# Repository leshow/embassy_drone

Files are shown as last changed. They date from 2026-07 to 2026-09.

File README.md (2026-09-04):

# mini quadcopter in Rust w/ embassy for esp32 and rp2350 (WIP)

currently still a work in progress, building a (very) mini quadcopter for esp32 on bare metal with [embassy.dev](https://embassy.dev). running on the esp32-s3 - the extra core lets the flight loop and WiFi run fully independently, and the hardware FPU matters a lot for the fusion/filter math.

## rp2350 brushless version

I've also started a version with brushless motors, a proper ESC and ELRS transmitter under [`brushless_rp2350/`](/brushless_rp2350). This one is currently WIP as well.

## Quad assets

drone frame

The frame stl & 3mf files are in the `stl/` dir and can be used to 3d print the frame. I created them in OnShape. For the battery compartment, I opted for a friction fit with pegs that you can also glue in. This got around some issues with printing supports that were a pain to remove.

There's a top stand that serves as a mount for the microcontroller and MPU6050 or ICM20948. I'll include a full parts list as the project progresses.

I've also created a prop guard you can mount as a single piece or in two halves, see the 3mf file in `stl/`

prop guard

They have a C-snap fit to the motor holders that should lock them into place pretty well. I've printed with a 0.4 and 0.6 nozzle on a bambu a1 and both results are usable. Obviously if you want cleaner layer lines go for the smaller nozzle.

I've printed in PLA, PETG and PETG-CF & GF. PLA seems totally fine, the drone frame is around ~13 grams. The prop guards are heavy at an additional 14 grams (I have a slimmed down version that still give some protection in the 3mf project file). Recommend running without the prop guards to get better battery and flight time.

## Parts list

### Microcontroller

S3-only - the earlier C3/C6 (RISC-V) builds were dropped in favor of the
S3's hardware FPU and second core. Needs the Xtensa toolchain (`espup`),
not plain `rustup` - see the ESP32-S3 section below for setup.

| Part | Chip | Cores  | Flash | RAM | WiFi | Notes |
| --- | --- | --- | ----- | --- | --- | --- |
| ESP32-S3 | ESP32-S3 | 2x LX7 | 4+ MB | 512K+PSRAM | 2.4 GHz | Current build - s3 feature |

### IMU Sensors (choose)

| Part | DOF  | Interface | Accel | Gyro | Mag | Notes |
| --- | ---- | --- | ----- | ---- | --- | --- |
| ICM-20948 | 9DOF | I²C / SPI | ✓ | ✓ | ✓ AK09916 | **Current build** - yaw via magnetometer |
| MPU-6050  | 6DOF | I²C | ✓ | ✓ | ✗ | No yaw reference; cheaper and common |

### Other Components

| Part | Qty | Notes |
| --- | --- | --- |
| 8520 brushed motor | 4 | find it on aliexpress like everything else |
| mosfet 100N03A | 4 | One per motor |
| 1S LiPo battery (3.7v) | 1 | 3.7v 1s battery 25C or more discharge rate\*  |
| Propeller | 4 | 55 or 65mm |
| 3D printed frame | 1 | STL/3MF files in `stl/` - designed in OnShape |

\*I tried with a 503040 3.7v lipo recycled from a keyboard build but the BMS (battery management system) on it will automatically shut off after a few seconds. It's not really build to power these motors.

### ESP32-S3 (default)

Needs the Xtensa toolchain, not plain `rustup`, plus [espflash](https://github.com/esp-rs/espflash) to flash and erase:

```sh
cargo install espup
espup install
# then source the exports it prints (or ~/export-esp.sh) before building

cargo install espflash
```

```sh
cargo build -p embassy_quad --target xtensa-esp32s3-none-elf
cargo run -p embassy_quad --target xtensa-esp32s3-none-elf
```

Or using the aliases:

```sh
cargo build-s3
cargo flash-s3
```

See .cargo/config.toml to see expansion of aliases

### Erase helpers

Two scripts in `scripts/` wrap `espflash erase-region` for the regions that come up most:

```sh
./scripts/erase-flash.sh        # wipes the app region (0x300000 bytes at 0x10000)
./scripts/erase-calibration.sh  # clears the nvs partition (0x6000 at 0x9000)
```

`erase-calibration` puts the accel back to "uncalibrated" by clearing partition table's `nvs`

### Log level

`DEFMT_LOG` is read at compile time by `esp-println`:

```sh
DEFMT_LOG=debug cargo flash-s3
```

### Throttle cap

`THROTTLE_CAP` sets the max throttle at compile time, it will map your throttle input from 0-100 over the range you specify. For example, if you set `THROTTLE_CAP=50` and push the throttle to 80% it will translate into `.8 * 50 = 40%`.

## Visualizer

to see a 3d rendering of the orientation run:

```bash
DEFMT_LOG="info" LOG_RATE_MS=1 cargo flash-s3 --features visualize | (cd visualizer && cargo run)
```

It feeds the esp32 log output to a binary reading stdin and rendering a cube on screen

Sensor readings from the ICM-20948 (over SPI) are sent to the ESP32-S3, where a Madgwick filter fuses accel and gyro data in software to correct orientation. (Earlier versions could also offload fusion to the ICM-20948's onboard DMP; that path has been dropped because DMP, although able to fuse mag input without calibration, is only capable of 100hz.) The icm20948's max speed is 1125hz.

```sh
DEFMT_LOG="info" LOG_RATE_MS=1 cargo flash-s3 --features visualize | (cd visualizer && cargo run)
```

## Ground control

The `ground_control/` crate is a PC-side sender that reads a gamepad and streams control packets to the drone over UDP.

The drone runs a wifi AP (`esp-quad`, WPA2) with a static IP of `192.168.4.1`. There is no DHCP server, so you must assign yourself a static IP when connecting. The trick is to do this in a single `nmcli con add` — adding security and static IP separately doesn't work reliably:

```sh
nmcli con add type wifi con-name esp-quad ssid esp-quad \
  wifi-sec.key-mgmt wpa-psk \
  wifi-sec.psk <same as AP_PASSWORD> \
  ipv4.method manual \
  ipv4.addresses "192.168.4.2/24" \
  ipv4.gateway "192.168.4.1"
```

The AP password is set at build time via the `AP_PASSWORD` environment variable. If unset, the AP is open (remove the `wifi-sec.*` lines above).

Once the profile exists, connecting is just:

```sh
nmcli dev wifi rescan
nmcli con up esp-quad
```

Then run the ground control sender:

```sh
cd ground_control && RUST_LOG="info" cargo run --release
```

The left stick Y axis controls throttle (center = 0%, full up = 100%), left stick X controls yaw, and the right stick controls pitch/roll. The Start button toggles arm. Motors only spin when armed and throttle is above 0.

The drone IP and port can be overridden at build time:

```sh
RUST_LOG="info" GATEWAY_IP=192.168.4.1 UDP_PORT=4444 cargo run --release
```

## Accelerometer Calibration

flash calibration:

```sh
DEFMT_LOG="debug" LOG_RATE_MS=100 AP_PASSWORD="testtest" cargo flash-s3 --features calibrate
```

You can then either leave the quad plugged in or unplug and calibrate using the wifi outputs, either way, you need to connect ground_control

after the `esp-quad` network shows up on wifi, connect to it and fire up ground control in calibration mode:

```sh
~/dev/rust/drone_embassy calibrate_on_wifi
❯ RUST_LOG="info" cargo gc -- --calibrate
    Finished `release` profile [optimized] target(s) in 0.02s
     Running `ground_control/target/x86_64-unknown-linux-gnu/release/ground_control --calibrate`
2026-07-19T04:19:17.472588Z  INFO ground_control: connected to 192.168.4.1:4444 - waiting to start calibration
2026-07-19T04:19:17.595122Z  WARN ground_control: place: level
2026-07-19T04:19:32.976684Z  WARN ground_control: place: front side up
2026-07-19T04:19:48.332827Z  WARN ground_control: place: back side up
2026-07-19T04:20:03.798211Z  WARN ground_control: place: right side up
2026-07-19T04:20:19.373504Z  WARN ground_control: place: left side up
2026-07-19T04:20:34.615814Z  WARN ground_control: place: upside down
2026-07-19T04:20:50.079828Z  INFO ground_control: === CALIBRATION COMPLETE - saved ===
```

follow the instructions and tilt the drone around the axis to get readings. The readings are saved in non-volatile flash memory on the esp32.

## Testing

Unit tests live in `libs`, the crate shared between `firmware` and `ground_control` that defines the control/telemetry packet wire formats. It's the only crate that can build for the host, `firmware` can't (esp-hal's build script refuses to build for a non-embedded target), so there's nothing to run tests against there yet.

`telemetry` and `telemetry-verbose` each change the telemetry packet's wire format, so they're tested separately:

```sh
cargo test -p libs
cargo test -p libs --features telemetry
cargo test -p libs --features telemetry-verbose
```

## Docs

Check the `docs/` directory for some more info on assembly, setting up different controllers, sensors, etc.

## LLM usage

Docs and tests are sometimes generated with the use of LLMs, along with explanation/discovery, but the purpose of this project is to actually learn, so the code is still written by a human (hi!)

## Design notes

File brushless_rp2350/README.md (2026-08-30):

# brushless mini quad on RP2350 (WIP)

Brushless follow-up to the main [esp32-s3 quad](../README.md) - same overall goal, different everything else. Individual ESCs instead of MOSFET-driven brushed motors, RP2350 instead of ESP32-S3, plain `rustup`/stable instead of the Xtensa toolchain, icm42688 IMU and happymodel EP2 radio instead of wifi.

Currently at the "runs fully off battery, all 4 motors spin via Oneshot125, EP2 bound to the RadioMaster Pocket" stage - no IMU, no mixer, and the control link isn't read by firmware yet (bound at the RF level, not yet parsed in code).

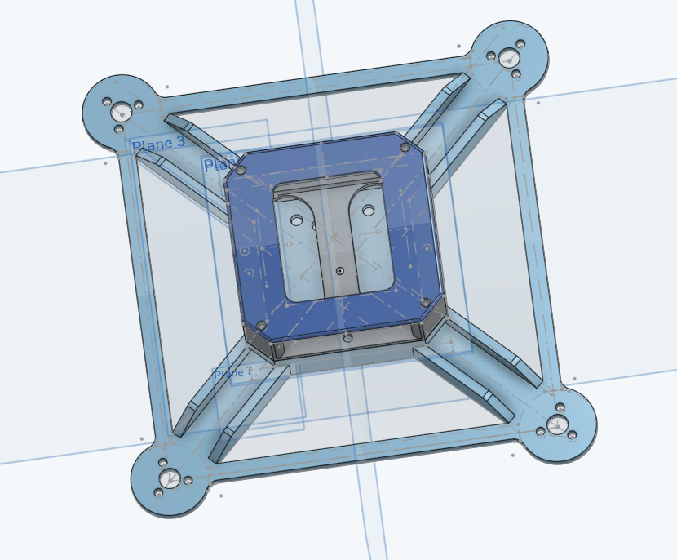
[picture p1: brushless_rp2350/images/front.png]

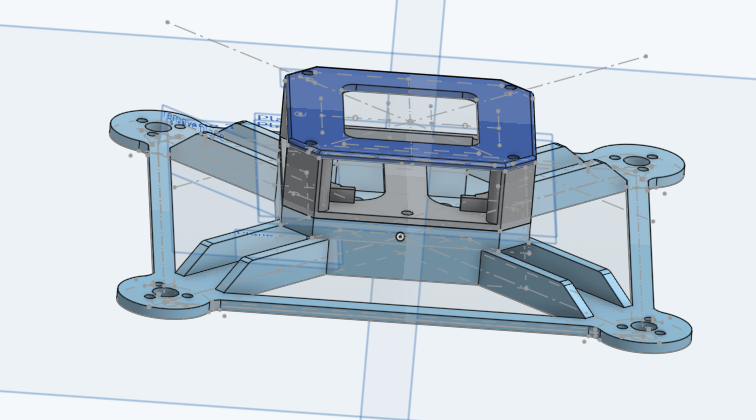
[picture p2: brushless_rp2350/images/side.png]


## Parts list (planned)

| Part | Qty | Notes |
| --- | --- | --- |
| RP2350 "mini zero" | 1 | Pro Micro-footprint clone, 29 GPIO broken out |
| Happymodel SE0802 19000KV | 4 | brushless motor, matches Mobula7 spec |
| MX-5A / MX-5A-L | 4 | individual 1S ESC, BLHeli_S/Bluejay ("BLS" in listing), one per motor |
| ICM-42688 | 1 | faster IMU |
| Happymodel Nano ELRS EP2 | 1 | ELRS receiver, CRSF over UART - pairs with the RadioMaster Pocket's built-in ELRS radio |
| 1S LiPo battery | 1 | |
| TPS63802 buck-boost module  | 1 | 1S -> 5V, powers RP2350 + EP2 - see Power section below |
| 3d printed frame in stl dir | 1 | ~70mm wheelbase, 45mm props |

## Status

- [x] single motor spins via standard servo-PWM on the bench (superseded, see below)
- [x] 4 of 4 motors spin via Oneshot125 on the bench (`src/main.rs`, GPIO10/11/12/13)
- [x] TPS63802 boost converter + EP2 wired up, whole system (RP2350 + motors) runs and arms/spins purely off battery, no USB - confirms the VSYS/power decision above works in practice
- [x] EP2 bound to the RadioMaster Pocket (solid LED) - RF link confirmed working end to end
- [x] all 4 motors + mixer (reusing `libs::mixer`)
- [x] IMU + fusion (reusing `libs::flight::fusion`)
- [x] DShot via PIO
- [ ] tune PID values

## Power

Two separate power domains:

- **Motors/ESCs**: direct off the 1S battery, unregulated - no boost converter in this path. Each MX-5A's power pads go straight to battery+/-, same raw-rail topology the brushed-motor build used minus the MOSFETs.
- **RP2350 + EP2 receiver**: 1S battery -> TPS63802 buck-boost module (5V output) -> RP2350's `VSYS` pin and the EP2's `+5V` pad, off the same boosted rail. Not `VBUS` - that's raw USB pass-through only, unavailable once flying off battery.

All grounds - battery, ESCs, RP2350, EP2, boost converter - share one common reference.

## Building

Standalone crate, not part of the root workspace - needs its own `stable` + `thumbv8m.main-none-eabihf` toolchain instead of the root's Xtensa `esp` channel.

```sh
cd brushless_rp2350
cargo build --release
```

Flash over USB/BOOTSEL (no debug probe needed - requires [picotool](https://github.com/raspberrypi/picotool)):

```sh
cargo flash-usb
```

Or, once SWD is soldered up to a debug probe, flash and get live `defmt` output:

```sh
cargo flash-probe
```

### Setting up the debug probe

For a Raspberry Pi Debug Probe or other CMSIS-DAP-compatible probe:

1. Install `probe-rs`: `cargo install probe-rs-tools --locked`
2. Linux udev rules, so the probe is accessible without root:

   ```sh
   sudo curl -fsSL https://probe.rs/files/69-probe-rs.rules -o /etc/udev/rules.d/69-probe-rs.rules
   sudo udevadm control --reload
   sudo udevadm trigger
   ```

3. Wire it up: use the probe's **"D"** (debug/SWD) port, not "U" (that's a separate plain UART). Standard 3-pin JST-SH cable: orange → SWCLK, black → GND, yellow → SWDIO. This board's SWD pins are bare pads, not a proper JST-SH connector, so you'll want the JST-SH-to-0.1"-header (female) cable variant to land on them.
4. SWD carries no power - the RP2350 still needs its own USB cable connected separately for power, same as the BOOTSEL/picotool path. So two USB cables total: one to the RP2350, one to the probe itself.
5. Raspberry Pi Debug Probes need firmware ≥2.2.0 for `probe-rs` to talk to them (older units commonly ship below that). Update via the [debugprobe releases page](https://github.com/raspberrypi/debugprobe/releases/latest): hold the probe's own BOOTSEL button while plugging it into USB, then copy `debugprobe.uf2` onto the mounted drive.
6. Sanity check before flashing: `probe-rs list` should show the probe.

See `.cargo/config.toml` for the alias definitions and notes on why the toolchain/tooling differs from the rest of the repo.

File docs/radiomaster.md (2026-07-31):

# RadioMaster Pocket as USB Gamepad for ground_control

How to configure a RadioMaster Pocket (EdgeTX) to act as a drop-in USB HID gamepad for `ground_control`, so the stick layout matches a regular Xbox-style controller with no code changes.

## Why this isn't plug and play

`ground_control` reads input through [gilrs](https://gitlab.com/gilrs-project/gilrs), which recognizes controllers by matching an SDL-style mapping database (Xbox controllers, PlayStation controllers, etc. are all in there). EdgeTX radios in USB joystick mode present a generic, fully configurable HID device under EdgeTX's own vendor ID, which is in nobody's mapping database.

Without a database entry, gilrs's Linux backend falls back to a fixed positional mapping based on the raw evdev axis/button codes (`native_ev_codes`):

| evdev code | gilrs axis/button |
| --- | --- |
| `ABS_X` | `Axis::LeftStickX`  |
| `ABS_Y` | `Axis::LeftStickY`  |
| `ABS_RX` | `Axis::RightStickX` |
| `ABS_RY` | `Axis::RightStickY` |
| `BTN_START` (0x13b)  | `Button::Start` |
| `BTN_SELECT` (0x13a) | `Button::Select` |

`ground_control` (`ground_control/src/main.rs`) maps those to controls:

- `LeftStickY` -> throttle
- `LeftStickX` -> yaw
- `RightStickX` -> roll
- `RightStickY` -> pitch
- `Button::Start` -> toggles armed (momentary press, matches a real Xbox controller's Start button)
- `Button::Select` -> armed follows the switch position directly (pressed = armed, released = disarmed), but only from a gamepad whose USB vendor/product id matches the Pocket's (`1209:4f54`) - so an Xbox controller's Back/View button, which also reports as `Button::Select`, can never trigger it

So the axis layout is just: configure the Pocket's USB joystick output to
match this table exactly, and gilrs/`ground_control` will treat it
identically to any other gamepad. The arm/disarm switch below relies on the
device-id check already built into `ground_control`, not on more config here.

## Use a dedicated Model

Do this setup in its own EdgeTX Model (Model Select screen), separate from any model you bind to a real receiver over ELRS later. Mixer, Outputs, and USB Joystick settings are all per-model in EdgeTX - nothing here can leak into a flight model, but it's one less thing to think about if the USB test config and the real flight config never share a save file.

## Advanced mode may not be available on your firmware

The instructions below assume EdgeTX's "Advanced" USB Joystick mode
(free-form per-channel axis/button picker, per-axis invert, Gamepad/Joystick
toggle). The Pocket uses an STM32F407xE chip with only 512KB flash, and since
EdgeTX 2.11 the build unconditionally disables this feature (`USBJ_EX`) for
that flash size because it doesn't fit
(`radio/src/targets/taranis/CMakeLists.txt`, confirmed in
[EdgeTX/edgetx#6434](https://github.com/EdgeTX/edgetx/issues/6434)). If the
USB Joystick page only shows Classic mode with no Advanced option, you're on
2.11+ and this is why - it's not a menu you're missing.

Three ways to proceed, roughly in order of effort:

1. **Flash EdgeTX 2.10.6** - the last release with Advanced mode intact on the
   Pocket. A normal firmware flash via EdgeTX Buddy/the bootloader, no
   building required. Since this is a new model anyway there's no old-model
   storage format to migrate. Back up the SD card first as a matter of
   course. Once on 2.10.6, follow the Advanced-mode steps below as written.
1. **Stay on stock 2.11+ firmware and use Classic mode instead** - no
   firmware changes at all, but more limited (fixed channel-to-axis order, no
   per-axis invert). See "USB Joystick setup - Classic mode" further down.

## USB Joystick setup - Advanced mode

1. Press MDL, page to SETUP
1. Set USB mode to **Advanced**
1. Set **Interface Mode** to **Gamepad**, not Joystick. This matters more than
   it sounds: Linux's HID driver maps HID button usages to a totally different
   evdev range depending on this setting (`BTN_TRIGGER`-family for Joystick,
   `BTN_SOUTH..BTN_THUMBR`-family for Gamepad). gilrs's fallback mapping only
   recognizes the Gamepad range, under Joystick mode, no button will ever
   register as `Button::Start`, no matter which number you pick.
1. In Channel Settings, assign axes by **which physical stick drives the
   channel**, not by channel number (channel order depends on your model's
   template/mode and won't match this table 1:1):

   | Control                              | Axis |
   | ------------------------------------ | ---- |
   | Rudder / yaw (left stick, horiz)     | X    |
   | Throttle (left stick, vert)          | Y    |
   | Aileron / roll (right stick, horiz)  | rotX |
   | Elevator / pitch (right stick, vert) | rotY |

   Leave every other channel `None` for now.

1. Arm/disarm: `ground_control` supports two independent controls here, wire
   up either or both:
   - **SE** (momentary button): a good fit precisely because it's momentary,
     not latching - each press cleanly toggles arm state without a mismatch
     between switch position and armed state. Pick a spare channel, set its
     source to SE, channel type **Btn**, button number **12** (HID button
     usage 12 -> evdev `BTN_START` -> gilrs `Button::Start`).
   - **SA** (2-position switch): a real latching switch, so `ground_control`
     treats it as a live level rather than a toggle - armed always matches
     SA's current position, up or down, even across a USB reconnect. Pick a
     different spare channel, set its source to SA, channel type **Btn**,
     button number **11** (HID button usage 11 -> evdev `BTN_SELECT` -> gilrs
     `Button::Select`).
1. If an axis reads backwards (e.g. throttle low at stick-up), use the invert
   control inside this same USB Joystick screen (not the Mixer's channel
   weight) - it only affects how the value is packaged into the HID report,
   not the underlying channel output other things (like a real RF link) would
   read.

After any change here, disconnect and reconnect USB, you may need to power cycle the controller too.

## USB Joystick setup - Classic mode

If you're staying on stock 2.11+ firmware (option 3 above), Classic mode has
no per-channel axis picker - it maps a fixed channel order onto axes and
buttons: **channel 1->X, 2->Y, 3->Z, 4->rotX, 5->rotY, 6->rotZ, 9-32->buttons
1-24** (button N = channel N+8). There's also no per-axis invert control - use
Mixer Weight/Offset on the channel instead. Interface Mode (Gamepad vs
Joystick) isn't selectable either, but that's fine: without `USBJ_EX` it's
hardcoded to Gamepad, which is what we want anyway (confirmed in the same
issue thread - someone without `USBJ_EX` had to hand-patch firmware source to
get Joystick type instead, meaning Gamepad is the compiled-in default).

Since Classic mode just reads whatever value ends up on a given channel
number, the trick is to **use the Mixer to put the right control on the right
channel number**, rather than assigning an axis to an existing channel:

1. In Model Setup (or Outputs page), set **Number of Channels** to at least
   **20** - channel 20 is needed for the arm button below, and the default
   model channel count usually doesn't go that high.
2. Turn off the internal/external RF module for this model (recommended by
   the EdgeTX manual for USB joystick use, and irrelevant anyway since this
   model is USB-only).
3. In the Mixer, set up these channels (delete/reassign whatever the default
   template put on CH1/2/4/5 first):

   | Channel | Source                               | -> Axis (Classic order)   |
   | ------- | ------------------------------------ | ------------------------- |
   | CH1     | Rudder / yaw (left stick, horiz)     | X                         |
   | CH2     | Throttle (left stick, vert)          | Y                         |
   | CH4     | Aileron / roll (right stick, horiz)  | rotX                      |
   | CH5     | Elevator / pitch (right stick, vert) | rotY                      |
   | CH19    | **SA** switch (2-position)           | button 11 -> `BTN_SELECT` |
   | CH20    | **SE** button (momentary)            | button 12 -> `BTN_START`  |

   Leave CH3, CH6-18 unassigned - Z/rotZ (CH3/CH6) aren't read by
   `ground_control`, and gilrs doesn't care about gaps in the button range.
   CH19/SA and CH20/SE are independent arm/disarm controls - wire up either
   or both. SE toggles arm on each press (momentary, so no
   switch-position/armed-state mismatch); SA's position is read live, so
   armed always matches wherever the switch currently sits.

4. If an axis reads backwards (e.g. throttle low at stick-up), fix it on the
   same Mixer line with **Weight -100%** instead of a dedicated invert
   control. Since this model is USB-only, inverting the real channel value
   here is fine - it doesn't feed a real RF link.
5. Optional: since a gamepad thumbstick springs back to center but the
   Pocket's throttle stick doesn't, you can use the _entire_ physical throttle
   throw for 0-100% instead of just the top half (which is what
   `ground_control` expects from a self-centering stick) by setting the CH2 mix to **Weight 50%,
   Offset +50** (adjust sign to taste). That compresses the full stick travel
   into the positive half of the reported axis, giving full resolution with
   no code changes. This trick works the same way regardless of Classic vs
   Advanced mode, since it's purely a Mixer-level rescale.

After any change here, disconnect and reconnect USB - you may need to power
cycle the controller too (see the USB wedge gotcha below).

## Verifying

Check the device enumerated correctly and has axes/buttons mapped right:

```sh
journalctl -k -n 100 | grep -i "radiomaster\|1209:4f54"
udevadm info -q property -n /dev/input/eventNN | grep ID_INPUT
```

You want to see `ID_INPUT_JOYSTICK=1`. If it's missing, the device has no axes/buttons configured yet.

Then run `ground_control` and watch its existing log lines while moving each stick and the arm button - `throttle:`, `roll:`, `pitch:`, `yaw:`, and `armed:` to confirm the mapping and polarity match a normal controller before flying anything.

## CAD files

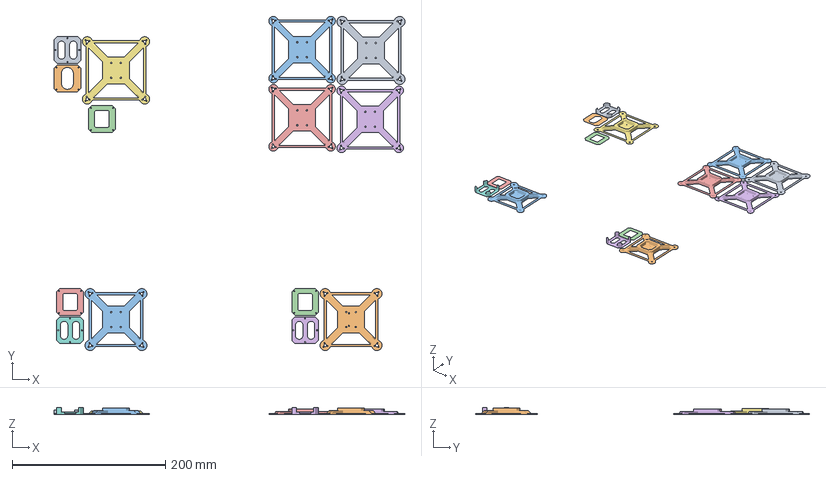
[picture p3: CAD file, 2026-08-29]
brushless_rp2350/stl/frame.3mf
458.7 x 436.7 x 9.00 mm
frame x 7
ESC x 4
top x 3

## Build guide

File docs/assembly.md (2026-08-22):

# Drone Assembly

## Parts

- ESP32-S3 board
- ICM-20948 IMU breakout
- 4× 100N03A N-channel MOSFET (one per motor)
- 4× 10kΩ resistor (gate pull-down, one per MOSFET)
- 4× 8520 brushed DC motor
- 3.3V buck-boost converter
- 2× 470μF electrolytic capacitor
- 1S LiPo battery (3.7V)
- 55mm or 65mm propellers

---

## Connection Tables

### Power

| From | To | Notes |
| --- | --- | --- |
| Battery + | Buck-boost converter IN+ | |
| Battery − | Buck-boost converter IN− | |
| Buck-boost converter 3.3V out | ESP32 3V3 pin | Feeds the S3 directly, bypassing VIN and the board's own onboard regulator - see Assembly Notes |
| Buck-boost converter GND | ESP32 GND | Common ground for all logic |
| 470μF cap (buck-boost) + | Buck-boost converter 3.3V out | Positive leg to 3.3V out |
| 470μF cap (buck-boost) − | Buck-boost converter GND | Prevents brownout during motor inrush |
| 470μF cap (battery) + | Battery + | Second cap, across the battery rail |
| 470μF cap (battery) − | Battery − | |
| Battery + | motor+ | Raw battery rail to motor switches - not through the buck-boost |
| Battery − / GND | All GND lines + mosfet source | Shared ground for motors and logic |

### ICM-20948 IMU (SPI)

Uses the ESP32-S3's actual dedicated IO_MUX FSPI pins (GPIO10-13), not
GPIO-matrix-routed ones - avoids the extra input-delay ceiling on reliable
SPI clock speed that GPIO-matrix routing would otherwise impose.

| ICM-20948  | ESP32-S3 | Notes |
| --- | --- | --- |
| VIN | 3.3V | Same net as the buck-boost's output into the ESP32-S3's 3V3 pin, tapped in parallel - not the board's own onboard regulator |
| GND | GND | |
| SDI (SDA)  | GPIO11 | SPI MOSI |
| SCLK (SCL) | GPIO12 | SPI clock |
| SDO (AD0)  | GPIO13 | SPI MISO - if AD0 was tied to a fixed level for I2C addressing, remove that tie, it's the same physical pin |
| nCS | GPIO10 | Actively driven by the ESP32, not tied to a fixed level - see Assembly Notes |
| INT | GPIO6 | Data-ready interrupt |

### Motors (via 100N03A MOSFET)

| Motor | Gate (ESP32) | Gate-Source | Drain | Source |
| --- | --- | --- | --- | --- |
| Front Left  | GPIO1 | 10k pull-down | Motor − | GND |
| Front Right | GPIO2 | 10k pull-down | Motor − | GND |
| Rear Left | GPIO4 | 10k pull-down | Motor − | GND |
| Rear Right  | GPIO3 | 10k pull-down | Motor − | GND |

Motor + on all four motors connects directly to Battery +. Motor − connects to MOSFET Drain.

---

## Wiring Diagrams

### ESP32-S3 Connections

```text
  Battery ──► [ Buck-Boost, 3.3V out ] ──► 3.3V rail
                                              │
          ┌───────────────────────┐          │
   3.3V ──┤ (NOT BAT+/-)          ├──► ICM-20948 VIN
    GND ──┤                       ├──► ICM-20948 GND
          │       ESP32-S3        │
 GPIO11 ──┤ MOSI                  ├──► ICM-20948 SDI
 GPIO12 ──┤ SCLK                  ├──► ICM-20948 SCLK
 GPIO13 ──┤ MISO                  ├──► ICM-20948 SDO
 GPIO10 ──┤ CS                    ├──► ICM-20948 nCS
  GPIO6 ──┤ INT                   ├──► ICM-20948 INT
          │                       │
  GPIO1 ──┤ FL PWM                ├──► MOSFET FL Gate
  GPIO2 ──┤ FR PWM                ├──► MOSFET FR Gate
  GPIO4 ──┤ RL PWM                ├──► MOSFET RL Gate
  GPIO3 ──┤ RR PWM                ├──► MOSFET RR Gate
          └───────────────────────┘
```

### Motor Layout (top-down view)

```text
                    FRONT
                      ▲
                      │
      FL (GPIO1)      │       FR (GPIO2)
         ◎────────────┼────────────◎
         │            │            │
         │       ┌────┴────┐       │
         │       │ICM20948 │       │
         │       └────┬────┘       │
         │            │            │
         ◎────────────┼────────────◎
     RL (GPIO4)       │       RR (GPIO3)
                      │
                      ▼
                     BACK
```

### MOSFET Wiring (per motor, repeated ×4)

```text
  Battery + ──────────────────────── Motor +
                                       │
                                    [Motor]
                                       │
                                    Motor − ──── Drain
                                              [100N03A]
  ESP32 GPIO ──────────── Gate         Source ──── GND
                        ┌──┘
                     [10kΩ]        pull-down holds gate low during boot/reset
                        └──┐
                          GND
```

---

## Assembly Notes

- ICM-20948 nCS must be actively driven by the ESP32 (GPIO10), not tied to a fixed level — SPI requires CS to toggle low to select the chip and high between transactions; a permanently-high CS means the sensor never responds. If your board previously had CS wired to 3.3V for I2C mode, that connection needs to change to the GPIO10 signal wire instead. A weak pull-up (~10kΩ) on the CS line is fine to leave in place as a power-up safety net — a proper push-pull GPIO output easily overrides it — but a hard direct wire to 3.3V must be removed, or the GPIO driving CS low would short against it
- ICM-20948 AD0/SDO is a shared pin — if AD0 was previously tied to a fixed level for I2C address selection, remove that tie before using this pin as an active SPI MISO output; the two functions share the same physical pin
- FSYNC (unused): tie to GND rather than leaving it floating — it's an edge-sensitive digital input, and a floating input near motor/ESC electrical noise can pick up spurious transitions even though nothing reads it currently
- The 10kΩ gate–source resistor on each MOSFET holds the gate low when the ESP32 GPIO is floating (boot/reset), preventing unintended motor spin-up
- MOSFETs are wired low-side: Drain to Motor −, Source to GND, Motor + connects directly to Battery +. N-channel MOSFETs cannot be used as high-side switches with a 3.3V gate signal
- Solder one 470μF electrolytic capacitor across the buck-boost's 3.3V output and GND, as close to those pads as possible (positive leg to 3.3V). This prevents the ESP32 from browning out during motor inrush current spikes
- Solder the second 470μF electrolytic capacitor across Battery + and Battery −, as close to the battery leads as possible (positive leg to Battery +). This buffers the raw battery rail against motor inrush current
- The buck-boost's output goes to the ESP32-S3's **3V3 pin**, not the board's BAT+/BAT- pads. BAT+/BAT- feeds the board's onboard LiPo charge-management IC, which expects a raw, unregulated cell for charging - feeding it an actively-regulated 3.3V from the buck-boost instead can make the charge IC fight the buck-boost's own regulation. Leave BAT+/BAT- disconnected
- All four MOSFET sources share GND; run a single wire to a bus point and branch from there
- Keep IMU signal wires (MOSI/SCLK/MISO/CS/INT) routed away from motor wires to reduce noise coupling — this matters more for SPI than I2C was, since GPIO-matrix routing and breadboard/jumper signal integrity both degrade at the multi-MHz clock rates SPI runs at
- The ESP32 3.3V pin (fed by the buck-boost) also powers the IMU; do not connect IMU VIN anywhere else

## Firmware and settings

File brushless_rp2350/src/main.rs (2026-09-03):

#![no_std]
#![no_main]

use crate::radio::Controls;
use defmt::{error, info};
use embassy_executor::{Executor, Spawner};
use embassy_rp::{
    bind_interrupts,
    gpio::{Level, Output},
    multicore::Stack,
    peripherals::PIO0,
    spi::{Config as SpiConfig, Spi},
    uart::InterruptHandler as UartInterruptHandler,
};
use embassy_sync::{blocking_mutex::raw::CriticalSectionRawMutex, watch};
use embassy_time::Instant;
use embedded_hal_bus::spi::ExclusiveDevice;

// only the feature-gated bench/visualize paths below need these - keeping them cfg'd off the
// normal build avoids unused-import warnings there
#[cfg(any(feature = "visualize", feature = "test_dshot"))]
use embassy_rp::Peri;
#[cfg(feature = "visualize")]
use embassy_rp::{
    gpio::{Input, Pull},
    peripherals::PIN_6,
};
#[cfg(feature = "test_dshot")]
use embassy_time::Timer;
#[cfg(feature = "visualize")]
use libs::flight::{
    fusion::{FusionBuilder, RAD_TO_DEG},
    sensors::ImuRead,
};
use static_cell::StaticCell;

use {defmt_rtt as _, panic_probe as _};

mod flight;
mod imu;
mod motors;
mod radio;

use motors::Motors;

// physical wiring
pub type MotorFl = embassy_rp::peripherals::PIN_10;
pub type MotorFr = embassy_rp::peripherals::PIN_11;
pub type MotorRl = embassy_rp::peripherals::PIN_12;
pub type MotorRr = embassy_rp::peripherals::PIN_13;

pub type RadioUart = embassy_rp::peripherals::UART0;
pub type RadioDma = embassy_rp::peripherals::DMA_CH0;
pub type ImuTxDma = embassy_rp::peripherals::DMA_CH1;
pub type ImuRxDma = embassy_rp::peripherals::DMA_CH2;

pub type CtrlRx<'a> = watch::Receiver<'a, CriticalSectionRawMutex, (Controls, Instant), 1>;
pub type CtrlTx<'a> = watch::Sender<'a, CriticalSectionRawMutex, (Controls, Instant), 1>;

bind_interrupts!(struct Irqs {
    UART0_IRQ => UartInterruptHandler<RadioUart>;
    DMA_IRQ_0 => embassy_rp::dma::InterruptHandler<RadioDma>, embassy_rp::dma::InterruptHandler<ImuTxDma>, embassy_rp::dma::InterruptHandler<ImuRxDma>;
    PIO0_IRQ_0 => embassy_rp::pio::InterruptHandler<PIO0>;
});

/// How many loop iterations to skip between log lines.
/// Override at build time: `LOG_RATE=200 cargo flash-s3` (default: 500).
const LOG_EVERY_N: u32 = {
    let every = match option_env!("LOG_RATE") {
        Some(s) => libs::flight::parse_u64(s),
        None => 500,
    };
    every as u32
};

/// cap on throttle for testing
const THROTTLE_CAP: u8 = {
    match option_env!("THROTTLE_CAP") {
        Some(s) => {
            let v = libs::flight::parse_u64(s);
            assert!(v <= 100, "THROTTLE_CAP must be 0..=100");
            v as u8
        }
        None => 100, // no cap default
    }
};

static mut CORE1_STACK: Stack<4096> = Stack::new();
static EX1: StaticCell<Executor> = StaticCell::new();

#[embassy_executor::main]
async fn main(_spawner: Spawner) {
    let p = embassy_rp::init(Default::default());

    #[cfg(feature = "test_dshot")]
    test_dshot(p.PIO0, p.PIN_10, p.PIN_11, p.PIN_12, p.PIN_13).await;

    #[cfg(feature = "visualize")]
    {
        // 3MHz, under ICM42688's 24MHz SPI ceiling

        use crate::imu::Sensor;
        let mut spi_config = SpiConfig::default();
        spi_config.frequency = 3_000_000;
        let spi_bus = Spi::new(
            p.SPI0, p.PIN_2, p.PIN_3, p.PIN_4, p.DMA_CH1, p.DMA_CH2, Irqs, spi_config,
        );
        let cs = Output::new(p.PIN_5, Level::High);
        let device = ExclusiveDevice::new_no_delay(spi_bus, cs).unwrap();

        // initialize() soft-resets the sensor and checks WHO_AM_I internally (expects 0x47)
        match Sensor::init(device).await {
            Ok(icm) => visualize(icm, p.PIN_6).await,
            Err(e) => error!("ICM42688 init failed: {}", e),
        }
    }

    // normal run scenario
    #[cfg(not(any(feature = "visualize", feature = "test_dshot")))]
    {
        use crate::{imu::Sensor, radio::CONTROLS};

        // radio gets core1 to itself - it's the chattiest task here (~250 frames/sec), and this
        // keeps its uart/dma work off the core running the 1kHz control loop
        embassy_rp::multicore::spawn_core1(
            p.CORE1,
            unsafe { &mut *core::ptr::addr_of_mut!(CORE1_STACK) },
            move || {
                let ex = EX1.init(Executor::new());
                ex.run(|spawner| {
                    spawner.spawn(
                        radio::read_radio(p.UART0, p.PIN_1, p.DMA_CH0)
                            .expect("failed to run radio"),
                    );
                });
            },
        );

        let mut spi_config = SpiConfig::default();
        spi_config.frequency = 3_000_000;
        let spi_bus = Spi::new(
            p.SPI0, p.PIN_2, p.PIN_3, p.PIN_4, p.DMA_CH1, p.DMA_CH2, Irqs, spi_config,
        );
        let cs = Output::new(p.PIN_5, Level::High);
        let device = ExclusiveDevice::new_no_delay(spi_bus, cs).unwrap();
        let rx = CONTROLS.receiver().expect("failed to create receiver");

        // motors first
        let motors = Motors::init(p.PIO0, p.PIN_10, p.PIN_11, p.PIN_12, p.PIN_13).await;

        // initialize() soft-resets the sensor and checks WHO_AM_I internally (expects 0x47)
        let mut sensor = match Sensor::init(device).await {
            Ok(icm) => icm,
            Err(e) => {
                error!("ICM42688 init failed: {}", e);
                // TODO: should this panic?
                return;
            }
        };
        // flush whatever backlog built up since init
        if let Err(e) = sensor.reset_fifo().await {
            error!("ICM42688 reset_fifo failed: {}", e);
        }
        flight::run(sensor, motors, p.PIN_6, rx).await;
    }

    info!("main exitied.");
}

// live fusion dump
// it can be piped into `visualizer` the same way the esp32-s3 project does:
// `cargo flash-probe --features visualize | (cd ../visualizer && cargo run)`
//
// INT1 (GPIO6) drives sampling off the data-ready pulse - ICM42688 config default is 200Hz
// ODR, latched/active-high, and read_sample()'s first SPI byte reads INT_STATUS which clears
// the latch
#[cfg(feature = "visualize")]
async fn visualize<D>(
    mut imu: crate::imu::Sensor<icm426xx::ICM42688<D, icm426xx::Ready>>,
    int1: Peri<'static, PIN_6>,
) where
    D: embedded_hal_async::spi::SpiDevice,
    D::Error: defmt::Format,
{
    let mut int1 = Input::new(int1, Pull::None);
    let mut fusion = FusionBuilder::new().icm42688().madgwick().build();
    let mut last = Instant::now();

    loop {
        // TODO: can try without wait_for_high if there are issues
        int1.wait_for_high().await;
        match imu.read().await {
            Ok((accel, gyro)) => {
                let now = Instant::now();
                let dt = now.duration_since(last).as_micros() as f32 / 1_000_000.0;
                last = now;

                let quat = fusion.update(dt, accel, gyro);
                let (roll, pitch, yaw) = quat.euler_angles();
                info!(
                    "roll: {}\u{b0} pitch: {}\u{b0} yaw: {}\u{b0}",
                    roll * RAD_TO_DEG,
                    pitch * RAD_TO_DEG,
                    yaw * RAD_TO_DEG
                );
            }
            Err(e) => error!("ICM42688 read_sample failed: {}", e),
        }
    }
}

// same GPIO10-13 wiring as test_oneshot, but driven through the real Motors abstraction
// (motors.rs) instead of raw PWM_SLICE5/6 - each motor gets its own independent PIO state
// machine. Motors::init already arms; unlike PWM (a free-running hardware counter that keeps
// outputting once configured), DShot frames are one-shot pushes to the PIO FIFO - nothing
// repeats on its own, so every phase (including the hold) has to keep calling set_motors at a
// steady rate or the ESCs will fail-safe
#[cfg(feature = "test_dshot")]
async fn test_dshot(
    pio: Peri<'static, PIO0>,
    fl: Peri<'static, MotorFl>,
    fr: Peri<'static, MotorFr>,
    rl: Peri<'static, MotorRl>,
    rr: Peri<'static, MotorRr>,
) {
    // Motors::set_motors takes normalized [0.0, 1.0], not raw DShot 0-1999 values
    const TARGET_THROTTLE: f32 = 0.2; // ~20%, same bench-spin level as the Oneshot125 test
    const RAMP_STEPS: u32 = 100;
    const HOLD_ITERATIONS: u32 = 100; // 100 * 20ms = 2s
    const STEP_DELAY_MS: u64 = 20;

    let mut motors = Motors::init(pio, fl, fr, rl, rr).await;

    // straight to target instead of ramping - diagnostic for whether the staggered start seen
    // during the ramp is just different motors crossing their own spin-up threshold at
    // different points along it, rather than a real per-channel timing difference
    info!("jumping straight to bench spin, no ramp");
    motors
        .set_motors(
            TARGET_THROTTLE,
            TARGET_THROTTLE,
            TARGET_THROTTLE,
            TARGET_THROTTLE,
        )
        .await;

    info!("holding bench spin");
    for _ in 0..HOLD_ITERATIONS {
        motors
            .set_motors(
                TARGET_THROTTLE,
                TARGET_THROTTLE,
                TARGET_THROTTLE,
                TARGET_THROTTLE,
            )
            .await;
        Timer::after_millis(STEP_DELAY_MS).await;
    }

    info!("ramping down to idle");
    for i in (0..=RAMP_STEPS).rev() {
        let t = TARGET_THROTTLE * (i as f32 / RAMP_STEPS as f32);
        motors.set_motors(t, t, t, t).await;
        Timer::after_millis(STEP_DELAY_MS).await;
    }

    motors.turn_off().await;
    info!("done, motors stopped");
}

// dead oneshot125 code. dshot is better :)
// #[cfg(feature = "test_oneshot")]
// {
//     let mut config = PwmConfig::default();
//     // RP2350 default sys clock is 150MHz - divider 150 makes 1 tick = 1us,
//     // top 299 makes one period 300us (~3.3kHz refresh) under
//     // Oneshot125's ~4kHz ceiling
//     config.divider = 150u8.into();
//     config.top = 299;
//     config.compare_a = ARM_US;
//     config.compare_b = ARM_US;

//     test_oneshot(
//         p.PWM_SLICE5,
//         p.PIN_10,
//         p.PIN_11,
//         p.PWM_SLICE6,
//         p.PIN_12,
//         p.PIN_13,
//         config,
//     )
//     .await;
// }
// Oneshot125 ESC convention: much faster refresh than standard PWM, pulse width in microseconds
// const ARM_US: u16 = 125;
// const BENCH_SPIN_US: u16 = 150; // 20% throttle: 125 + 0.20 * (250 - 125)
// min + (percent * (max - min))

// async fn test_oneshot(
//     slice_a: Peri<'static, PWM_SLICE5>,
//     pin_10: Peri<'static, MotorFl>,
//     pin_11: Peri<'static, MotorFr>,
//     slice_b: Peri<'static, PWM_SLICE6>,
//     pin_12: Peri<'static, MotorRl>,
//     pin_13: Peri<'static, MotorRr>,
//     mut config: PwmConfig,
// ) {
//     // gpio 10/11 on pwm_slice5
//     let mut esc_fl_fr = Pwm::new_output_ab(slice_a, pin_10, pin_11, config.clone());
//     // gpio 12/13 are on pwm slice 6 - PIN_12 is hardware-fixed as channel A, PIN_13 as
//     // channel B (must be passed in that order), so compare_a controls GPIO12 (RL) and
//     // compare_b controls GPIO13 (RR)
//     let mut esc_rl_rr = Pwm::new_output_ab(slice_b, pin_12, pin_13, config.clone());

//     info!("arming ESCs, holding min throttle");
//     Timer::after_secs(2).await;

//     // straight to target instead of ramping - PWM's a free-running hardware counter, so unlike
//     // DShot there's no failsafe-timeout concern either way; this matches what the direct-jump
//     // DShot test already confirmed: the staggered start seen during a slow ramp was just
//     // different motors crossing their own spin-up threshold at different points along it
//     info!("jumping straight to bench spin, no ramp");
//     config.compare_a = BENCH_SPIN_US;
//     config.compare_b = BENCH_SPIN_US;
//     esc_fl_fr.set_config(&config);
//     esc_rl_rr.set_config(&config);

//     info!("holding bench spin");
//     Timer::after_secs(2).await;

//     info!("ramping down to idle");
//     for us in (ARM_US..=BENCH_SPIN_US).rev() {
//         config.compare_a = us;
//         config.compare_b = us;
//         esc_fl_fr.set_config(&config);
//         esc_rl_rr.set_config(&config);
//         Timer::after_millis(100).await;
//     }

//     config.compare_a = ARM_US;
//     config.compare_b = ARM_US;
//     esc_fl_fr.set_config(&config);
//     esc_rl_rr.set_config(&config);
//     info!("done, idling at min throttle");
// }

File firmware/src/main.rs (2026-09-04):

#![allow(clippy::too_many_arguments)]
#![cfg_attr(feature = "calibrate", allow(unused))]
#![no_std]
#![no_main]
extern crate alloc;

use defmt::info;
use embassy_executor::Spawner;
use embassy_time::Timer;
use embedded_hal_bus::spi::ExclusiveDevice;
use esp_backtrace as _;
use esp_hal::{
    Async, gpio,
    interrupt::software::SoftwareInterruptControl,
    ledc::{
        LSGlobalClkSource, Ledc, LowSpeed,
        timer::{self, TimerIFace, config::Duty},
    },
    peripherals::LEDC,
    spi::master::Spi,
    system::Stack,
    time::Rate,
    timer::timg::TimerGroup,
};
use esp_println as _;
use esp_rtos::embassy::Executor;
use static_cell::StaticCell;

esp_bootloader_esp_idf::esp_app_desc!();

mod calibration_storage;
mod flight;
mod motors;
mod panic_safety;
mod sensors;
mod wifi;

use crate::{motors::Motors, sensors::Sensor};
use libs::flight::AccelBias;

const LOOP_PERIOD_MS: u64 = 1; // 1000Hz target loop rate; shared by timer and Madgwick sample_period
// if changing duty cycle, change this value. currently 10 bit resolution
const PWM_BITS: u32 = 10;
const PWM_MAX_DUTY: u32 = (1 << PWM_BITS) - 1;

static TIMER: StaticCell<timer::Timer<'static, LowSpeed>> = StaticCell::new();

/// How many loop iterations to skip between log lines.
/// Override at build time: `LOG_RATE_MS=200 cargo flash-s3` (default: 500 ms).
const LOG_EVERY_N: u32 = {
    let ms = match option_env!("LOG_RATE_MS") {
        Some(s) => libs::flight::parse_u64(s),
        None => 500,
    };
    (ms / LOOP_PERIOD_MS) as u32
};

/// cap on throttle for testing
const THROTTLE_CAP: u8 = {
    match option_env!("THROTTLE_CAP") {
        Some(s) => {
            let v = libs::flight::parse_u64(s);
            assert!(v <= 100, "THROTTLE_CAP must be 0..=100");
            v as u8
        }
        None => 100, // no cap default
    }
};

const fn pwm_duty_config(bits: u32) -> Duty {
    match bits {
        1 => Duty::Duty1Bit,
        2 => Duty::Duty2Bit,
        3 => Duty::Duty3Bit,
        4 => Duty::Duty4Bit,
        5 => Duty::Duty5Bit,
        6 => Duty::Duty6Bit,
        7 => Duty::Duty7Bit,
        8 => Duty::Duty8Bit,
        9 => Duty::Duty9Bit,
        10 => Duty::Duty10Bit,
        11 => Duty::Duty11Bit,
        12 => Duty::Duty12Bit,
        13 => Duty::Duty13Bit,
        14 => Duty::Duty14Bit,
        _ => panic!("failed to pick PWM duty"),
    }
}

type SpiSensor<'a> = ExclusiveDevice<Spi<'a, Async>, gpio::Output<'a>, embassy_time::Delay>;

#[cfg(feature = "mag")]
pub(crate) type Sensor20948<'a> = Sensor<
    icm20948_async::Icm20948<icm20948_async::SpiDevice<SpiSensor<'a>>, icm20948_async::MagEnabled>,
>;

#[cfg(not(feature = "mag"))]
pub(crate) type Sensor20948<'a> = Sensor<
    icm20948_async::Icm20948<icm20948_async::SpiDevice<SpiSensor<'a>>, icm20948_async::MagDisabled>,
>;

// runs on core 1: everything WiFi-related. Kept off core 0 so the flight loop never competes
// with WiFi/UDP tasks for time on a shared executor. measured on the old single-core c3:
// disabling the wifi spawn entirely dropped i2c read from ~1.12ms to ~979us avg, a dedicated
// core buys the same isolation without giving up wifi
#[cfg(not(feature = "visualize"))]
#[embassy_executor::task]
async fn wifi_core_task(wifi: esp_hal::peripherals::WIFI<'static>, spawner: Spawner) {
    let ap = wifi::AP::init(wifi, spawner).await;
    #[cfg(not(feature = "calibrate"))]
    ap.listen_control(spawner);
    #[cfg(feature = "calibrate")]
    ap.listen_calibrate(spawner);
}

#[esp_rtos::main]
async fn main(_spawner: Spawner) {
    // WiFi tasks get their own spawner on core 1 (see wifi_core_task) - core 0's spawner is
    // unused since main() drives the flight loop directly rather than spawning it as a task
    let peripherals = esp_hal::init(esp_hal::Config::default());

    // wifi heap only needed when running the AP, visualize mode just logs over USB
    #[cfg(not(feature = "visualize"))]
    {
        esp_alloc::heap_allocator!(#[esp_hal::ram(reclaimed)] size: 64 * 1024);
        esp_alloc::heap_allocator!(size: 36 * 1024);
    }

    let sw_int = SoftwareInterruptControl::new(peripherals.SW_INTERRUPT);
    let timg0 = TimerGroup::new(peripherals.TIMG0);
    esp_rtos::start(timg0.timer0, sw_int.software_interrupt0);

    #[cfg(not(feature = "visualize"))]
    {
        static APP_CORE_STACK: StaticCell<Stack<8192>> = StaticCell::new();
        let app_core_stack = APP_CORE_STACK.init(Stack::new());

        esp_rtos::start_second_core(
            peripherals.CPU_CTRL,
            sw_int.software_interrupt1,
            app_core_stack,
            move || {
                static EXECUTOR: StaticCell<Executor> = StaticCell::new();
                let executor = EXECUTOR.init(Executor::new());
                executor.run(|core1_spawner| {
                    core1_spawner.spawn(wifi_core_task(peripherals.WIFI, core1_spawner).unwrap());
                });
            },
        );
    }

    // Wait for ICM20948 to power up before touching SPI at all
    Timer::after_millis(1000).await;

    // S3's actual IO_MUX FSPI pins - not GPIO-matrix routed, so no repeat of the C3 matrix-input
    // -delay ceiling that capped reliable SPI clock there. GPIO10=CS, GPIO11=MOSI, GPIO12=SCLK,
    // GPIO13=MISO, GPIO6=interrupt, GPIO1-4=motors (front left/front right/rear right/rear left)
    let spi = Spi::new(
        peripherals.SPI2,
        esp_hal::spi::master::Config::default().with_frequency(Rate::from_mhz(3)), // 3mhz sems reliable, faster crashed whoami on imu startup
    )
    .expect("failed to start spi")
    .with_sck(peripherals.GPIO12)
    .with_mosi(peripherals.GPIO11)
    .with_miso(peripherals.GPIO13)
    .into_async();

    let cs = gpio::Output::new(
        peripherals.GPIO10,
        gpio::Level::High,
        gpio::OutputConfig::default(),
    );
    let spi_device = ExclusiveDevice::new(spi, cs, embassy_time::Delay)
        .expect("failed to create SPI exclusive device");

    // normal run scenario
    #[cfg(not(any(feature = "calibrate", feature = "visualize")))]
    {
        let int_pin = gpio::Input::new(peripherals.GPIO6, gpio::InputConfig::default());
        run(
            spi_device,
            peripherals.LEDC,
            peripherals.FLASH,
            peripherals.GPIO4, // rear left
            peripherals.GPIO3, // rear right
            peripherals.GPIO1, // front left
            peripherals.GPIO2, // front right
            int_pin,
        )
        .await;
    }

    // calibrate and write to nvs
    #[cfg(feature = "calibrate")]
    {
        // ICM20948
        let mut sensor = Sensor::init_icm20948(spi_device)
            .await
            .expect("ICM20948 init failed");
        let mut flash_storage = esp_storage::FlashStorage::new(peripherals.FLASH);
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

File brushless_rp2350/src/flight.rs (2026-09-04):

use crate::{CtrlRx, motors::Motors};
use defmt::{debug, error, info};
use embassy_rp::{
    Peri,
    gpio::{Input, Pull},
    peripherals::PIN_6,
};
use embassy_time::{Duration, Instant};

use {defmt_rtt as _, panic_probe as _};

use libs::flight::{
    filters,
    fusion::{FusionBuilder, RAD_TO_DEG},
    pid::Pid,
    sensors::ImuRead,
};
use nalgebra::Vector3;

mod vals {
    use libs::flight::fusion;

    // max roll/pitch command from stick (+/- 25 deg)
    pub const MAX_TILT_RAD: f32 = 25.0 * fusion::DEG_TO_RAD;

    // outer loop p gains
    pub const ANGLE_P_ROLL_PITCH: f32 = 2.0;
    // and angle_p_yaw means the controller will eventually torque
    // quad to chase drift
    pub const ANGLE_P_YAW: f32 = 0.0;

    // inner loop - only P is live for the first test. D and I come in one at a time, in that
    // order, once the previous term is confirmed stable. INTEGRAL_LIMIT/LEAK below stay
    // inert while their Ki is 0 - both only ever shape the accumulator's value, and Ki=0
    // zeroes that value's contribution to the output regardless
    pub const RATE_KP_ROLL_PITCH: f32 = 0.05;
    pub const RATE_KI_ROLL_PITCH: f32 = 0.0; // was 0.3
    pub const RATE_KD_ROLL_PITCH: f32 = 0.0; // was 0.001

    pub const RATE_KP_YAW: f32 = 0.0; // flix 0.3 was set to 0.2
    pub const RATE_KI_YAW: f32 = 0.0; // was 0.05
    pub const RATE_KD_YAW: f32 = 0.0; // was 0.001

    pub const INTEGRAL_LIMIT: f32 = 0.3;
    // per-second decay on the rate pids' integral term - without this, any permanent small error
    // eventually winds the integral to integral_limit given enough time, no matter how small the error is. with
    // decay, a persistent error settles at an equilibrium of error/rate_integral_leak instead,
    // while a genuinely larger disturbance still gets proportionally more integral authority
    pub const RATE_INTEGRAL_LEAK: f32 = 1.0;

    // outer loop angle error deadband - a resting tilt under this is mounting tolerance subtracts the band rather than clamping to it, so there's
    // no discontinuity in commanded rate right at the edge. roll/pitch only: yaw can't wind up
    // (rate_ki_yaw = 0) and has its own heading-hold handling already
    pub const ANGLE_DEADBAND_RAD: f32 = 0.5 * fusion::DEG_TO_RAD;
}

mod util {

    pub(crate) fn deadband(x: f32, band: f32) -> f32 {
        if x > band {
            x - band
        } else if x < -band {
            x + band
        } else {
            0.0
        }
    }

    // normalises an angle to [-pi, pi] for the shortest-path yaw error
    pub(crate) fn wrap_angle(a: f32) -> f32 {
        use core::f32::consts::PI;
        // fmodf gives the same sign as the dividend, so shift into [0, 2pi) before subtracting back
        let r = libm::fmodf(a + PI, 2.0 * PI);
        (if r < 0.0 { r + 2.0 * PI } else { r }) - PI
    }

    // running min/max/avg of loop dt between periodic log lines - lets the actual loop rate be
    // checked without needing per-tick logging
    pub struct DtStats {
        pub min: f32,
        pub max: f32,
        pub sum: f32,
        pub n: u32,
    }

    impl DtStats {
        pub const fn new() -> Self {
            Self {
                min: f32::MAX,
                max: 0.0,
                sum: 0.0,
                n: 0,
            }
        }

        pub fn record(&mut self, dt: f32) {
            self.min = self.min.min(dt);
            self.max = self.max.max(dt);
            self.sum += dt;
            self.n += 1;
        }

        pub fn avg(&self) -> f32 {
            self.sum / self.n as f32
        }
    }
}

pub async fn run<'a, D>(
    mut sensor: crate::imu::Sensor<icm426xx::ICM42688<D, icm426xx::Ready>>,
    mut motors: Motors<'a>,
    int1: Peri<'static, PIN_6>,
    mut rx: CtrlRx<'a>,
) where
    D: embedded_hal_async::spi::SpiDevice,
    D::Error: defmt::Format,
{
    let mut log_count: u32 = 0;
    let mut int1 = Input::new(int1, Pull::None);
    let mut fusion = FusionBuilder::new().icm42688().madgwick().build();
    let mut last = Instant::now();
    let mut dt_stats = util::DtStats::new();
    let mut accel_filter = filters::Lpf3::new_two_pole(filters::ACCEL_LPF_HZ);
    // TODO: delete me
    // norm of every accel sample over a log window, plus how many the health gate threw out.
    // this is the measurement that says whether vibration is actually reaching the estimator
    let mut accel_stats = util::DtStats::new();
    let mut accel_rejects: u32 = 0;

    // inner rate PIDs
    let mut roll_pid = Pid::new(
        vals::RATE_KP_ROLL_PITCH,
        vals::RATE_KI_ROLL_PITCH,
        vals::RATE_KD_ROLL_PITCH,
        vals::INTEGRAL_LIMIT,
        vals::RATE_INTEGRAL_LEAK,
    );
    let mut pitch_pid = Pid::new(
        vals::RATE_KP_ROLL_PITCH,
        vals::RATE_KI_ROLL_PITCH,
        vals::RATE_KD_ROLL_PITCH,
        vals::INTEGRAL_LIMIT,
        vals::RATE_INTEGRAL_LEAK,
    );
    let mut yaw_pid = Pid::new(
        vals::RATE_KP_YAW,
        vals::RATE_KI_YAW,
        vals::RATE_KD_YAW,
        vals::INTEGRAL_LIMIT,
        vals::RATE_INTEGRAL_LEAK,
    );

    let mut target_yaw: f32 = 0.0;
    let mut yaw_init = false;
    let mut last_armed = false;

    loop {
        int1.wait_for_high().await;

        // gyro still goes in raw - no LPF or bias tracking on it yet unlike esp32s3
        let (accel, gyro) = match sensor.read().await {
            Ok(sample) => sample,
            Err(e) => {
                error!("ICM42688 read_sample failed: {}", e);
                continue;
            }
        };

        let now = Instant::now();
        let dt = now.duration_since(last).as_micros() as f32 / 1_000_000.0;
        last = now;
        dt_stats.record(dt);

        // the chip's anti-alias filter is set to 1/2 the imu ODR (currently 1khz)
        // everything below that arrives unfiltered
        // madgwick uses accel as its gravity reference, so a corrupted sample tilts the estimate
        // and the angle loop below then chases it with real motor output
        let accel = accel_filter.update(accel, dt);

        // outside this band the reading isn't gravity, it's vibration or motion, so its direction
        // can't be trusted as "down" no matter how smooth it is. feeding zeros makes madgwick
        // treat it as "no accel this tick" and coast on gyro integration instead of being pulled
        // by a bad reference
        let accel = if (filters::ACCEL_HEALTHY_MIN..=filters::ACCEL_HEALTHY_MAX).contains(&{
            let accel_norm = accel.norm();
            accel_stats.record(accel_norm);
            accel_norm
        }) {
            accel
        } else {
            accel_rejects += 1;
            Vector3::zeros()
        };

        let quat = fusion.update(dt, accel, gyro);
        let (actual_roll, actual_pitch, actual_yaw) = quat.euler_angles();
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

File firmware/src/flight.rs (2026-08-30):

use embassy_time::{Duration, Instant};
use esp_hal::gpio;
#[cfg(feature = "telemetry")]
use libs::telemetry::TelemetryPacket;
use nalgebra::{UnitQuaternion, Vector3};

use crate::{Motors, Sensor20948, wifi};
pub use libs::flight::AccelBias;
#[cfg(feature = "mag")]
use libs::flight::fusion::MargFusion;
use libs::flight::sensors::ImuRead;
#[cfg(feature = "mag")]
use libs::flight::sensors::ImuReadMag;
use libs::flight::{filters, fusion, fusion::ImuFusion, pid::Pid};

// publishes a telemetry snapshot for the wifi udp_task to reply with on the next control packet.
// called once per loop iteration, from whichever exit point (early continue or full mix) is
// actually taken, so telemetry is only ever built once per tick.
#[cfg(all(feature = "telemetry", not(feature = "telemetry-verbose")))]
fn publish_telemetry(
    euler: (f32, f32, f32),       // (roll, pitch, yaw) radians
    motors: (u16, u16, u16, u16), // fl fr rl rr
    armed: bool,
    failsafe: bool,
) {
    let roll_deg = euler.0 * fusion::RAD_TO_DEG;
    let pitch_deg = euler.1 * fusion::RAD_TO_DEG;
    let yaw_deg = euler.2 * fusion::RAD_TO_DEG;

    let pkt = TelemetryPacket::new(roll_deg, pitch_deg, yaw_deg, motors, armed, failsafe);
    wifi::TELEMETRY.lock(|c| c.set(Some((pkt, Instant::now()))));
}

// publishes a telemetry snapshot for the wifi udp_task to reply with on the next control packet.
// called once per loop iteration, from whichever exit point (early continue or full mix) is
// actually taken, so telemetry is only ever built once per tick.
#[cfg(feature = "telemetry-verbose")]
#[allow(clippy::too_many_arguments)]
fn publish_telemetry(
    euler: (f32, f32, f32),       // (roll, pitch, yaw) radians
    motors: (u16, u16, u16, u16), // fl fr rl rr
    armed: bool,
    failsafe: bool,
    gyro: Vector3<f32>,
    torques: Vector3<f32>,   // roll/pitch/yaw PID output before mixing
    gyro_bias: Vector3<f32>, // current BiasTracker estimate, zero on the DMP path
    dt: f32,                 // seconds since the previous loop tick
    accel: Vector3<f32>,     // bias + mount-trim corrected accel in g, zero on the DMP path
) {
    let roll_deg = euler.0 * fusion::RAD_TO_DEG;
    let pitch_deg = euler.1 * fusion::RAD_TO_DEG;
    let yaw_deg = euler.2 * fusion::RAD_TO_DEG;

    let pkt = TelemetryPacket::new(
        roll_deg, pitch_deg, yaw_deg, motors, armed, failsafe, gyro, torques, gyro_bias, dt, accel,
    );
    wifi::TELEMETRY.lock(|c| c.set(Some((pkt, Instant::now()))));
}

// same field set as publish_telemetry's verbose variant, logged locally over defmt trace
// instead of published over wifi - unconditional on the telemetry feature, so dt/attitude/etc
// stay visible with wifi telemetry compiled out entirely. free at the default DEFMT_LOG=info
// (see .cargo/config.toml) - trace! compiles down to a no-op unless DEFMT_LOG=trace is set
#[allow(clippy::too_many_arguments)]
fn trace_telemetry(
    euler: (f32, f32, f32),       // (roll, pitch, yaw) radians
    motors: (u16, u16, u16, u16), // fl fr rl rr
    armed: bool,
    failsafe: bool,
    gyro: Vector3<f32>,
    torques: Vector3<f32>,   // roll/pitch/yaw PID output before mixing
    gyro_bias: Vector3<f32>, // current BiasTracker estimate, zero on the DMP path
    dt: f32,                 // seconds since the previous loop tick
    accel: Vector3<f32>,     // bias + mount-trim corrected accel in g, zero on the DMP path
) {
    defmt::trace!(
        "telemetry roll={}° pitch={}° yaw={}° armed={} failsafe={} | motors fl={} fr={} rl={} rr={} | gyro x={} y={} z={} | torques roll={} pitch={} yaw={} | bias x={} y={} z={} | dt={} | accel x={} y={} z={}",
        euler.0 * fusion::RAD_TO_DEG,
        euler.1 * fusion::RAD_TO_DEG,
        euler.2 * fusion::RAD_TO_DEG,
        armed,
        failsafe,
        motors.0,
        motors.1,
        motors.2,
        motors.3,
        gyro.x,
        gyro.y,
        gyro.z,
        torques.x,
        torques.y,
        torques.z,
        gyro_bias.x,
        gyro_bias.y,
        gyro_bias.z,
        dt,
        accel.x,
        accel.y,
        accel.z,
    );
}

// max roll/pitch command from stick (+/- 25 deg)
const MAX_TILT_RAD: f32 = 25.0 * fusion::DEG_TO_RAD;

// outer loop P gains
const ANGLE_P_ROLL_PITCH: f32 = 4.0; // flix 6.0
// and angle_p_yaw means the controller will eventually torque
// quad to chase drift. we can enable it when we get mag working
const ANGLE_P_YAW: f32 = 0.0; // flix 3.0

// weak "assume roughly level" prior, applied every tick regardless of accel health - bounds
// roll/pitch drift during the stretches where the accel gate rejects the sample and nothing
// else is correcting the estimate (measured in some flight tests: gate rejects 53-81% of samples with
// motors spinning). matches flix's levelWeight - see libs::level_correction for the actual math
// and its tests. weight is a fixed fraction applied per TICK, not per second (same
// property flix's own filter turned out to have), so the real half-life depends on however fast
// the loop actually runs.
#[allow(dead_code)] // apply_level_prior call is temporarily commented out for a timing test
const LEVEL_PRIOR_WEIGHT: f32 = 0.0002;

// inner loop
const RATE_KP_ROLL_PITCH: f32 = 0.05; // flix 0.05
const RATE_KI_ROLL_PITCH: f32 = 0.3; // flix 0.2 was set to 0.1
const RATE_KD_ROLL_PITCH: f32 = 0.001; // flix 0.001

const RATE_KP_YAW: f32 = 0.3; // flix 0.3 was set to 0.2
const RATE_KI_YAW: f32 = 0.05;
const RATE_KD_YAW: f32 = 0.001;

const INTEGRAL_LIMIT: f32 = 0.3;
const BETA_FILTER: f32 = 0.1;
// per-second decay on the rate PIDs' integral term - without this, any permanent small error
// (mounting tolerance, an uneven resting surface - there's always something) eventually winds
// the integral to integral_limit given enough time, no matter how small the error is. With
// decay, a persistent error settles at an equilibrium of error/RATE_INTEGRAL_LEAK instead,
// while a genuinely larger disturbance still gets proportionally more integral authority
const RATE_INTEGRAL_LEAK: f32 = 1.0;
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

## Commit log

2026-07-27 many changes...
    - adds to telemetry-verbose
    - sets up wifi calibration
    - adds software LPF for rate/accel
    - accel bias filter
    - changes to ground_control to reconnect better.
    - lots more docs added by claude by reading through betaflight +
    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
2026-07-31 just pre swapping creates
    [flight.rs, main.rs, motors.rs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]
2026-08-05 Revise weight information and recommendations in README
    Updated weight details for drone frame and prop guards, and added recommendation for flight without prop guards.
2026-08-05 Update README with ICM-20948 DMP details
    Clarified explanation of ICM-20948 sensor data fusion and its limitations.
2026-08-06 fix actions for esp32s3
    [main.rs]
2026-08-14 add rp2350 brushless project as well
    [frame.3mf]
2026-08-21 brushless motor spinning oneshot125
    [frame.3mf]
2026-08-22 get rp2350 debug probe working
2026-08-22 update assembly for esp32 drone
2026-08-24 get fourth motor spinning
    [frame.3mf]
2026-08-27 add visualize mode to rp2350 & icm42688 sensor
    [frame.3mf]
2026-08-28 switch to dshot
    [frame.3mf]
2026-08-29 add motor mixer for dshot
    [frame.3mf]
2026-08-29 add Sensor to rp2350
2026-09-03 move erase-flash and erase-calibraton to scripts
